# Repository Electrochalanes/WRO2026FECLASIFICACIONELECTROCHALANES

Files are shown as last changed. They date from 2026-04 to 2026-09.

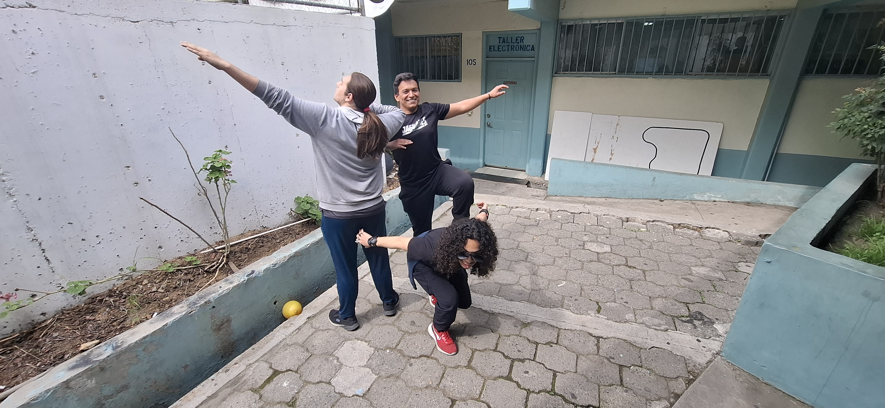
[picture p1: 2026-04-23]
t-photos/funnyphoto.jpg

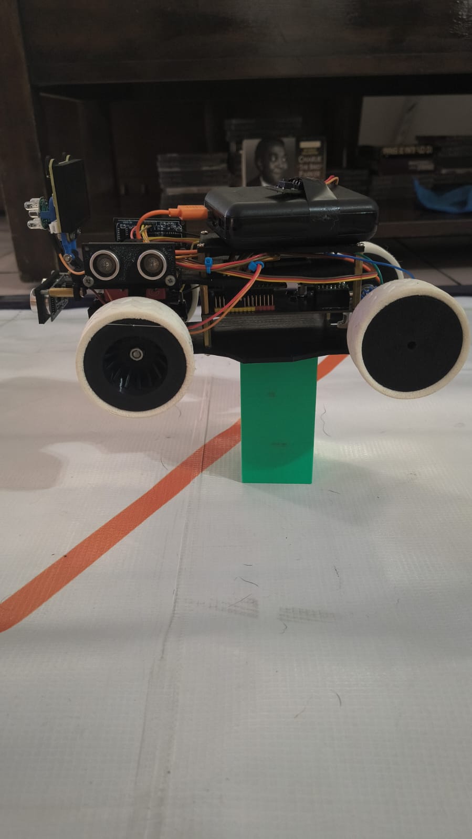
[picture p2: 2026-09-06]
v-photos/left.jpeg

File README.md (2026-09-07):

# Electrochalanes — WRO Future Engineers 2026 - Autonomous Self-Driving Car 🇲🇽

---

## Team

**Electrochalanes** — Tijuana, Baja California, Mexico

---

## Changelog

| Version | Date scope | Key changes |
|---|---|---|
| v1.0 | 2025 national competition | Baseline chassis, standard steering, single lateral sensor (Arduino UNO). |
| v2.0 | Early 2026 season | Bilateral PID (left + right sensors), Ackermann steering geometry, TPU tires, WonderCam color-based turn detection. |
| **v3.0 (current)** | **2026 Nationals** | **Migrated main controller from Arduino UNO R4 Minima to ESP32 + custom shield. Chassis and steering linkage reprinted in black PETG. Open Challenge control strategy rewritten (camera removed, adaptive single-wall PID). Obstacle Challenge gained a parking-exit maneuver and a two-tier (proportional + full-evasion) pillar strategy. Robot assembly video added.** |

This section exists specifically to give reviewers a fast way to see what changed between hardware/software revisions, in addition to the detailed reasoning in each section below.

---

## Repository Contents

| Folder | Contents |
|---|---|
| `t-photos` | 2 team photos (official + fun) |
| `v-photos` | 6 vehicle photos (all sides, top and bottom) |
| `video` | `video.md` with links to autonomous driving demonstrations for both challenges, **plus a full step-by-step robot assembly video** |
| `schemes` | Wiring and electromechanical diagrams (including the custom ESP32 shield) |
| `src` | Complete, commented control software for all programmed components |
| `models` | 3D-printable STL files for custom vehicle parts (now sliced for black PETG) |

---

## Introduction

This repository documents the complete engineering process of our autonomous vehicle for the **WRO Future Engineers 2026**.

As of this revision, the vehicle's main controller is an **ESP32** dev board paired with a **custom shield** (see [Components](#components) and [Power and Sensor Architecture](#2-power-and-sensor-architecture)), replacing the Arduino UNO R4 Minima used previously. The control software is split into two independent sketches, one per challenge:

**Open Challenge** (`src/OpenChallengeNationalsCode.ino`) is organized around:
1. **Sensor module** — sequential HC-SR04 readings (front, left, right)
2. **Adaptive single-wall PID controller** — follows whichever side wall was closer at the start of the run
3. **Corner-direction & turn sequencer** — determines and executes 90° turns using ultrasonic data only (the WonderCam camera is **no longer used** in this challenge — see [Open Challenge — Software Architecture](#open-challenge--software-architecture))
4. **Lap/corner counter and final-stop routine**

**Obstacle Challenge** (`src/ObstaclesChallengeNationalsCode.ino`) is organized around:
1. **Sensor module** — HC-SR04 front/left/right + push-button start trigger
2. **Vision module** — WonderCam color detection (red/green traffic pillars)
3. **Two-tier evasion strategy** — proportional visual steering while a pillar is far away, full stop-reverse-swerve maneuver once it's close
4. **Corner FSM** — 90° turns with a reverse/repositioning phase
5. **Parking-exit sequencer** *(new)* — multi-phase maneuver to leave the starting parking box in the direction with more clearance
6. **Lap/corner counter and stop routine**

To compile and upload either sketch: install **Arduino IDE 2.x**, add the **ESP32 board package** ("esp32" by Espressif Systems, via Boards Manager → additional URL `https://raw.githubusercontent.com/espressif/arduino-esp32/gh-pages/package_esp32_index.json`), install the **ESP32Servo** library (the standard `Servo` library is not compatible with the ESP32's PWM/LEDC peripheral) and, for the Obstacle Challenge sketch only, the **WonderCam** library. Open the corresponding `.ino` file, select your board's exact ESP32 dev-module variant, choose the correct COM port, and click Upload. Serial output is enabled at 115200 baud for live debugging via the Arduino IDE Serial Monitor.

---

## Components

| Component | Model | Purpose |
|---|---|---|
| Main controller | **ESP32 dev board** (WROOM-32-based DevKit) | Central processing — sensor reading, PID, motor and servo control |
| **Custom shield** | **Team-designed** | Consolidates all wiring (motor driver, servo, 3× HC-SR04, WonderCam I²C bus, start button) onto a single board mounted on the ESP32's headers, in place of the breadboard wiring used with the Arduino UNO R4 Minima. See [Power and Sensor Architecture](#2-power-and-sensor-architecture) for the electrical reasoning behind it. |
| DC motor driver | TB6612FNG Dual Motor Driver | Bidirectional speed control via PWM |
| Drive motor | 50:1 Micro Metal Gearmotor HPCB 6V | Forward traction |
| Steering servo | Digital Servomotor TD-8125 | Directional control via Ackermann steering |
| Ultrasonic sensor ×3 | HC-SR04 | Front wall detection + wall-following / corner detection |
| Color camera | Hiwonder WonderCam V2.0 | Detects red/green traffic pillars (Obstacle Challenge only) |
| Start button | Push button (Pin 34, `INPUT_PULLUP` + external pull-up on the shield) | Triggers start sequence per WRO rules 9.10–9.11 |
| Logic power | 5V 3A power bank | Supplies the ESP32, sensors, camera, and servo |
| Motor power | 7.4V 400 mAh LiPo | Dedicated traction supply, isolated from logic |
| Structure | **Black PETG** (chassis frame, sensor mounts, steering linkage), TPU (tires), acrylic (base plate), M3/M5 screws, M5/M16 bearings | Chassis, tires, and mechanical assembly |

> **Note on the ESP32 dev board model:** any WROOM-32-based ESP32 DevKit-style board works with the pin map used in the sketches (GPIOs 5, 12–14, 17–19, 21, 22, 32–35). If your team's exact board/module differs, update this row with the precise part number and add its pinout diagram to `schemes/`.

### Why ESP32 instead of the Arduino UNO R4 Minima?

| Consideration | Arduino UNO R4 Minima | ESP32 | Why it mattered for us |
|---|---|---|---|
| Clock speed / headroom | 48 MHz | 240 MHz (dual-core) | More margin for the camera-driven decision logic in the Obstacle Challenge sketch, without slowing down sensor polling. |
| GPIO count | Limited | More available I/O | Needed extra pins once the parking-exit and dual-servo-pin-mapping requirements were added. |
| Native PWM/servo support | `Servo` library, hardware timers shared with other peripherals | Dedicated LEDC PWM peripheral via `ESP32Servo` | Frees up timer conflicts we previously had to work around. |
| I/O voltage | 5V-tolerant | **3.3V-only** | Introduced a real integration risk — see the level-shifting note below. |

**Engineering risk introduced by the migration (and why the custom shield exists):** the HC-SR04's ECHO output is a 5V logic signal, but every ESP32 GPIO is rated for 3.3V input only — driving an ECHO pin directly from a 5V sensor risks damaging the microcontroller over repeated use. Additionally, GPIO34 (used for the start button) is one of the ESP32's *input-only* pins and, unlike most other GPIOs, has **no internal pull-up/pull-down resistor at all**, so `pinMode(PIN_BOTON, INPUT_PULLUP)` in software does not actually provide one. The custom shield exists to solve both problems in one board: resistor voltage dividers on the three ECHO lines (stepping 5V down into the ESP32's safe range) and an external pull-up resistor on the button line, in addition to simply consolidating what used to be loose breadboard wiring. 

### Shield Design and Power Distribution

No commercial board combines an ESP32 with a TB6612FNG H-bridge in the footprint we needed — the few options that exist are either pin-incompatible or considerably larger than necessary. Rather than continuing to wire both onto a breadboard, we designed our own pin-expansion shield: laid out like any commercial ESP32 shield, but with its header arrangement built specifically around the H-bridge.

**How it's wired:**
- Power comes in through a barrel jack or the USB-C port.
- That input feeds a regulator that steps 5V down to the ESP32's native 3.3V logic supply.
- The ESP32's header pins are fed directly from the unregulated input rail rather than through that regulator, so raw 5V is still available at the header for peripherals that need it, separate from the ESP32's own regulated 3.3V.
- A few ESP32 GPIOs are wired exclusively to the TB6612FNG and aren't broken out to the general-purpose header at all; the driver needs them, so they're still fully usable from code, just not available for anything else on the shield.
- The TB6612FNG's logic side shares the ESP32's rail, but the motor supply comes directly from the main power input, bypassing the regulator.
---

## 1. Mobility and Mechanical Design

### Chassis and Steering System

The vehicle's structure is based on our 2025 national competition design, with an **Ackermann steering geometry** on the front axle. Ackermann geometry ensures that during a turn, the inner wheel follows a tighter arc than the outer wheel — eliminating lateral tire slip and reducing friction in tight corners. This improves trajectory repeatability, which is critical when relying on a time-based turn duration instead of a gyroscope.

**Material update (v3.0):** the chassis frame, sensor mounts, and the **steering linkage rod** are now printed in **black PETG**, replacing the PLA used previously. Compared to PLA, PETG has meaningfully higher impact resistance and layer adhesion, at a modest cost in stiffness and print-surface finish — a favorable trade for the steering rod specifically, since it is a component under repeated cyclical mechanical stress every time the Ackermann linkage moves. Tires remain **TPU** (grip and vibration absorption).

M3 screws handle small brackets and sensor attachments; M5 screws with M5/M16 bearings handle the steering pivot and rear axle, ensuring low friction under load.

### Drive Motor Selection

The **50:1 Micro Metal Gearmotor HPCB 6V** (0.74 kg·cm stall torque, ~650 rpm no-load) was selected after evaluating two options:

| Option | Ratio | Speed | Torque | Result |
|---|---|---|---|---|
| **Chosen: HPCB 6V 50:1** | 50:1 | ~650 rpm | 0.74 kg·cm | ✅ Sufficient torque, controllable speed for closed-loop control |
| Discarded: high-speed motor | 10:1 | ~3000 rpm | ~0.15 kg·cm | ❌ Too fast — the control loop could not correct lateral drift in time |

The 50:1 ratio provides enough torque to accelerate smoothly while keeping speed low enough for the wall-following controller to react before lateral drift exceeds recoverable limits. This reasoning is unchanged by the ESP32 migration; the motor and driver stage were not modified.

### Iteration History

| Version | Change | Reason |
|---|---|---|
| V1 (2025) | Standard steering, single lateral sensor | Baseline from 2025 national competition |
| V2 | Bilateral PID using left + right sensors | V1 drifted toward the wider wall; bilateral error fixed this |
| V3 | Ackermann steering geometry, TPU tires | Standard steering caused ~8° corner angle error per turn due to tire slip |
| **V4 (current)** | **ESP32 + custom shield; black PETG chassis and steering rod; Open Challenge vision removed in favor of adaptive single-wall PID; Obstacle Challenge gained a parking-exit maneuver** | **More processing headroom and I/O for the added parking-exit logic; PETG's toughness over PLA for the steering linkage; simplifying the Open Challenge control loop by removing a camera dependency that wasn't needed once the sensor-only cornering logic proved reliable** |

---

## 2. Power and Sensor Architecture

### Power Budget

Two independent power rails isolate motor switching noise from logic and sensor signals. Figures below are typical component ratings for this hardware revision; **please re-verify with a multimeter on your actual assembled shield**, since exact draw depends on the ESP32 board variant and shield regulation.

**Rail 1 — Logic (5V, 3A power bank):**

| Component | Current (approx.) |
|---|---|
| ESP32 dev board (Wi-Fi/Bluetooth unused) | ~150 mA |
| WonderCam V2.0 *(Obstacle Challenge sketch only)* | ~300 mA |
| 3× HC-SR04 sensors | ~45 mA total (~15 mA each) |
| TD-8125 servo (peak) | ~1,500 mA |
| TB6612FNG logic stage | <10 mA |
| **Total peak — Obstacle Challenge (camera active)** | **~2,005 mA** |
| **Total peak — Open Challenge (no camera in this sketch)** | **~1,705 mA** |

Servo peaks are short and do not coincide with ESP32 or camera peaks, so worst-case sums are conservative.

**Rail 2 — Traction (7.4V, 400 mAh LiPo):**

| Component | Current |
|---|---|
| 50:1 gearmotor (peak) | ~1,500 mA |
| TB6612FNG power stage | ~100 mA |
| **Total peak** | **~1,600 mA** |

Estimated autonomy: 0.4 Ah ÷ 1.6 A = **~15 minutes** — more than sufficient for 3-minute runs. This estimate is unchanged from the previous hardware revision, since the traction rail was not modified.

> **Why two rails?** During early testing, motor acceleration caused voltage dips on a shared supply that reset the microcontroller mid-run. Splitting into two independent rails eliminated this failure mode entirely, and the same reasoning carried over unchanged to the ESP32 migration.

### Sensor Selection and Placement

**Why HC-SR04?**
The HC-SR04 is a widely available, cost-effective sensor with a well-documented standard protocol (10 µs HIGH trigger pulse, echo read on HIGH), reliable performance at the distances used in this competition (10–200 cm), and straightforward integration via `pulseIn`. Its main integration cost on this hardware revision is the 5V/3.3V logic mismatch discussed above, addressed via the custom shield's level shifting.

| Sensor | Position | Height | Justification |
|---|---|---|---|
| Front | Center-front of chassis | 12 cm | Avoids reading the floor; detects walls reliably from the corner-trigger distance used by each challenge |
| Left | Above front-left wheel | 10 cm | Reads lateral wall distance for wall-following; positioned forward to detect walls before the chassis passes them |
| Right | Above front-right wheel | 10 cm | Symmetric to left, used interchangeably depending on which side the controller decides to follow |

The WonderCam (Obstacle Challenge only) is mounted facing forward/down, positioned to detect red and green traffic pillars ahead of the vehicle and to compute each pillar's horizontal position and bounding-box area.

### Pin Map

The two sketches assign a few pins differently, because the Obstacle Challenge sketch needs the ESP32's default I²C pins (GPIO21/22) for the WonderCam, while the Open Challenge sketch is free to use GPIO21 for the servo instead:

| Signal | Open Challenge | Obstacle Challenge |
|---|---|---|
| Front TRIG / ECHO | 33 / 19 | 33 / 19 |
| Right TRIG / ECHO | 18 / 5 | 18 / 5 |
| Left TRIG / ECHO | 32 / 35 | 32 / 35 |
| Steering servo | **21** | **17** |
| I²C SDA / SCL (WonderCam) | *not used* | **21** / 22 |
| Start button | 34 | 34 |
| Motor PWM / AIN1 / AIN2 | 14 / 12 / 13 | 14 / 12 / 13 |

---

## Open Challenge — Software Architecture

The Open Challenge no longer uses the WonderCam at all. Turn direction and lane-keeping are both derived purely from the three HC-SR04 sensors. This is a deliberate simplification from the previous camera-based approach: once the sensor-only cornering logic (comparing which side opens up at a corner) proved reliable in testing, the camera dependency added complexity without adding accuracy for this challenge, so it was removed. The Obstacle Challenge sketch still uses the camera, since it needs to identify pillar *color*, which distance sensors cannot do.

### Control Flow

```
                     ┌────────────────────────┐
                     │  IDLE (button not yet   │
                     │  pressed)                │
                     └───────────┬─────────────┘
                                 │ button press
                                 ▼
                   Capture initial left/right distance
                   as PID setpoints → follow whichever
                   side is CLOSER for the whole run
                                 │
                                 ▼
                     ┌────────────────────────┐
             ┌──────►│   WALL-FOLLOWING PID    │
             │       │ (single sensor, fixed   │
             │       │  setpoint from start)   │
             │       └───────────┬─────────────┘
             │                   │ front < DISTANCIA_GIRO
             │                   │ AND one side opens up
             │                   ▼
             │       ┌────────────────────────┐
             │       │   CORNER TURN           │
             │       │ (first corner picks &   │
             │       │  locks the direction;   │
             │       │  later corners repeat   │
             │       │  the same direction)    │
             │       └───────────┬─────────────┘
             │                   │ corner count < 12
             └───────────────────┘
                                 │ corner count == 12
                                 ▼
                     Drive straight briefly, stop
```

### Algorithm 1 — HC-SR04 Sequential Reading

All three sensors are read one at a time every loop cycle:

```cpp
float leerDistancia(int trig, int echo) {
  digitalWrite(trig, LOW);
  delayMicroseconds(2);
  digitalWrite(trig, HIGH);
  delayMicroseconds(10);          // HC-SR04: 10 µs HIGH pulse to trigger
  digitalWrite(trig, LOW);
  unsigned long duracion = pulseIn(echo, HIGH, 30000);   // 30 ms timeout -> ~5 m max range
  if (duracion == 0) return -1;
  return duracion / 58.0;         // standard HC-SR04 time-of-flight -> cm conversion
}
```

A reading of `-1` (timeout) is treated as "no update" rather than "wall is very far": the loop only overwrites `ulLecturaFrente/Der/Izq` when a reading is valid, so a single dropped echo doesn't erase a good previous reading.

### Algorithm 2 — Adaptive Single-Wall PID

Rather than the previous bilateral (left-minus-right) centering controller, this revision follows **one wall only**, chosen at the start of the run:

```cpp
// At start: capture each side's distance as that side's setpoint
setpoint_Der = (ulLecturaDer < 400) ? ulLecturaDer : 40.0;
setpoint_Izq = (ulLecturaIzq < 400) ? ulLecturaIzq : 40.0;

// Whichever side is CLOSER (smaller setpoint) is the one that gets followed
if (setpoint_Der > setpoint_Izq) {
  opcion_2 = 1;   // right wall is farther -> follow the (closer) left wall
} else {
  opcion_2 = 2;   // left wall is farther (or equal) -> follow the (closer) right wall
}
```

```cpp
void PIDderecho() {
  error = ulLecturaDer - setpoint_Der;

  double P = Kp * error;
  double D = Kd * ((error - error_anterior) / dt);
  // Conditional integration: only accumulate the integral if doing so keeps
  // the *unclamped* output inside the same band the final output is
  // clamped to — a simple anti-windup trick.
  double prueba = P + D + Ki * (suma_errores + error * dt);
  if (constrain(prueba, -20, 20) == prueba) {
    suma_errores += error * dt;
    suma_errores = constrain(suma_errores, -70, 70);
  }
  double I = Ki * suma_errores;
  double salidaPID = constrain(P + I + D, -20, 20);

  int anguloServo = CENTRO + (int)salidaPID;
  moverServo(anguloServo);
  adelante(VEL_NORMAL);
  error_anterior = error;
}
```

`PIDizquierdo()` mirrors this exactly, with the error sign flipped (`setpoint_Izq - ulLecturaIzq`) so that a positive PID output always means "steer right" under both functions, using the same gains and clamps.

**Why adaptive-setpoint single-wall following instead of bilateral centering?** Bilateral centering (error = left − right) is setpoint-free and adapts automatically to any corridor width, which is why V2 used it. The trade-off is that it requires both sensors to be reliable simultaneously. The single-wall approach trades that generality for simplicity: it commits to one wall at the start (whichever is closer, and therefore whichever gives a stronger, more reliable signal) and only needs that one sensor to behave well for the rest of the run. This is a deliberate simplification, not strictly an improvement — teams reproducing this design should note it assumes a roughly consistent corridor width within a round, since a mid-run corridor-width change would not be compensated for the way bilateral centering would.

**Tuning (current gains):**

| Kp | Ki | Kd |
|---|---|---|
| 10.0 | 0.05 | 5.0 |

Note these gains are **not directly comparable in magnitude** to the previous bilateral controller's `Kp=1.2, Ki=0.04, Kd=0.15`, since the earlier controller's error term was the difference of two sensors (typically small, since both sides are similar magnitudes) while this one's error term is a single sensor's raw deviation in cm from a fixed setpoint (potentially larger swings) — a like-for-like re-tune was required after the algorithm change, not just a hardware swap.

### Algorithm 3 — Turn Direction and Cornering (Sensor-Only)

A corner is recognized when the front sensor reads closer than `DISTANCIA_GIRO` (80 cm) **and** at least one lateral sensor reads more than 100 cm — the second condition distinguishes an actual corner opening from simply being close to a wall in a narrow straight.

```cpp
if (opcion == 0) {
  // First corner: stop, let the chassis settle, then re-read both sides
  detenerRobot();
  delay(1500);
  float lIzq = leerDistancia(TRIG_IZQ, ECHO_IZQ);
  float lDer = leerDistancia(TRIG_DER, ECHO_DER);
  if (lIzq > 0) ulLecturaIzq = lIzq;
  if (lDer > 0) ulLecturaDer = lDer;

  // Turn toward whichever side has more open space — that's where the track continues
  if (ulLecturaIzq > ulLecturaDer) {
    opcion = 1;       // more room on the left -> turn left at every corner from now on
    girarIzquierda();
  } else {
    opcion = 2;       // more room on the right -> turn right at every corner from now on
    girarDerecha();
  }
} else if (opcion == 1) {
  girarIzquierda();   // keep the same direction as the first corner
} else if (opcion == 2) {
  girarDerecha();
}
```

`girarIzquierda()`/`girarDerecha()` are open-loop, timed maneuvers: steer to full lock, drive through the corner for `TGIRO` ms, recenter, then drive straight for `TFront` ms before the PID loop resumes (this last step gives the chassis room to clear the corner before its lateral readings are trusted again).

This replaces the previous WonderCam-based turn detection entirely. There is no fallback path needed here (unlike the old camera-based version, whose fallback *was* this same sensor comparison) — this **is** now the only mechanism.

### Edge Cases

| Situation | Behavior |
|---|---|
| Front sensor timeout (`-1`) mid-run | Last known-good front reading is kept; a corner is not spuriously triggered by a single dropped echo |
| Both lateral sensors read ≥ 400 cm at start | Both setpoints default to 40 cm |
| `dt` computed as ~0 (very fast consecutive loop iterations) | Clamped to a 0.001 s minimum to avoid a divide-by-zero in the derivative term |
| 12th corner completed | Drives straight for `TFinal` ms to clear the area, then stops for good |

---

## Obstacle Challenge — Software Architecture

### Overview

The Obstacle Challenge program combines: a start-of-run **parking-exit maneuver**, a **two-tier pillar-evasion strategy** driven by the WonderCam, and a **corner FSM** for the track's 90° turns. A lap counter (`contadorGiros`) tracks completed corners; after 12 corners (3 laps) the run stops.

### Priority Order

Each `loop()` pass (throttled to ~10 Hz for the decision logic, while sensors are still polled every cycle) evaluates, in order:

1. **Start button** — arms the robot and, on the very first press, triggers the parking-exit maneuver (per WRO rule: the vehicle must not move until the operator releases it)
2. **Color detection & evasion decision** — if either pillar color is in view, this branch takes over exclusively for that cycle
3. **Corner detection** — only checked when no pillar is currently in view; triggers the corner FSM if the front wall is close and a side is open

### Corner FSM

```
DRIVING STRAIGHT ──(front < DISTANCIA_FRENTE AND a side is open)──► TURN (steer to lock, drive Tgiro ms)
                                                                          │
                                                                (pause Talto ms)
                                                                          │
                                                                          ▼
                                                                REVERSE, wheel angled
                                                                (Tatras ms)
                                                                          │
                                                                          ▼
                                                        contadorGiros++ → DRIVING STRAIGHT
                                                        (if contadorGiros == 12 → STOP)
```

```cpp
void girarDerecha() {
  moverServo(Acentral + 40);
  adelante(VELOCIDAD_GIRO);
  delay(Tgiro);
  moverServo(Acentral);
  detenerRobot();
  delay(Talto);
  moverServo(Areversa);        // wheel angled while reversing, to help straighten the heading
  atras(VELOCIDAD_GIRO);
  delay(Tatras);
  detenerRobot();
  delay(500);
  adelante(VELOCIDAD_NORMAL);
  moverServo(Acentral);
  delay(1000);
}
```

`girarIzquierda()` mirrors this for left turns.

### Algorithm — Two-Tier Pillar Evasion

Rather than a single fixed-distance trigger, the current logic reacts differently depending on how close a pillar is:

- **Far away** (bounding-box area below threshold): a light **proportional** nudge keeps the pillar roughly centered in frame, without committing to a full evasion yet:
  ```cpp
  int angulo = map(centroX, 0, 320, 51, 111);
  moverServo(constrain(angulo, 51, 111));
  adelante(VELOCIDAD_NORMAL);
  ```
- **Close enough** (bounding-box area above threshold): a full 3-phase evasion maneuver runs — reverse briefly, swerve past the pillar on the rule-mandated side, drive straight, then swerve back to center:
  ```cpp
  void esquivarRojo() {          // passes a RED pillar on the RIGHT, per WRO rules
    detenerRobot();
    delay(500);
    atras(VELOCIDAD_NORMAL);
    delay(500);
    detenerRobot();
    delay(500);
    adelante(VELOCIDAD_ESQUIVE);
    moverServo(AesquiveRojo + 10);
    delay(Tesquive);
    adelante(VELOCIDAD_ESQUIVE);
    moverServo(Acentral);
    delay(Tcentral);
    adelante(VELOCIDAD_ESQUIVE);
    moverServo(AreacomodoRojo - 10);
    delay(Treacomodo + 200);
    moverServo(Acentral);
  }
  ```
  `esquivarVerde()` mirrors this, steering left instead, to pass a **GREEN** pillar on the **LEFT** — also per WRO rules.

### Algorithm — Parking-Exit Maneuver *(new)*

On the first button press, the robot reads which side of the parking box has more clearance and executes a fixed 5-phase sequence to back out of it — the same alternating forward/reverse, opposite-lock pattern a person uses to exit a tight parallel parking spot:

| Phase | Action | Steering | Duration |
|---|---|---|---|
| 1 | Forward | Full lock, away from the box | `Tadelante_salida` (350 ms) |
| 2 | Reverse | Full lock, opposite way | `Tatras_salida` (300 ms) |
| 3 | Forward | Full lock, away from the box | `Tadelante_afuera` (1000 ms) |
| 4 | Forward | Full lock, opposite way | `Tadelante_afuera` (1000 ms) |
| 5 | Reverse | Full lock, away from the box | `Tatras_Acomodo` (600 ms) |

```cpp
void salirEstacionamientoDerecha() {
  moverServo(Asalida_derecha);
  adelante(Velocidad_salida);
  delay(Tadelante_salida);
  detenerRobot();
  delay(500);
  moverServo(Asalida_izquierda);
  atras(Velocidad_salida);
  delay(Tatras_salida);
  detenerRobot();
  delay(500);
  moverServo(Asalida_derecha);
  adelante(Velocidad_salida);
  delay(Tadelante_afuera);
  detenerRobot();
  delay(500);
  moverServo(Asalida_izquierda);
  adelante(Velocidad_salida);
  delay(Tadelante_afuera);
  detenerRobot();
  delay(500);
  moverServo(Asalida_derecha);
  atras(Velocidad_salida);
  delay(Tatras_Acomodo);
  detenerRobot();
}
```

`salirEstacionamientoIzquierda()` is the mirror image, used when the left side has more clearance. Whichever side is chosen here (`opcion`) is reused for every corner turn direction for the rest of the run, keeping the exit direction and the lap direction consistent.

**Known scope limitation:** after the 12th corner, the robot simply stops where it is — there is currently no automated maneuver to return to and re-park inside the parking box. This is a reasonable next iteration if the team wants to pursue the final-parking bonus described in the rulebook (Section 6, "Estacionamiento en el cajón de estacionamiento").

### Edge Cases

| Situation | Behavior |
|---|---|
| Green detection too low in frame (`centroY2 > 150`) | Treated as noise (block likely already alongside/behind the robot) and its area is zeroed out |
| Pillar detected while mid-corner-turn | Corner maneuvers are blocking (`delay`-based), so a pillar can't interrupt one already in progress |
| No pillar and no corner condition | Drive straight at `VELOCIDAD_NORMAL`, keep polling |
| Camera update fails (`Cam.updateResult()` returns false) | Cycle is skipped (`return`) rather than acting on stale/garbage data |

---

## Obstacle Challenge — Source Code

The complete, commented source for both challenges lives at:
- `src/open_challenge/OpenChallengeNationalsCode.ino`
- `src/obstacle_challenge/ObstaclesChallengeNationalsCode.ino`

---

## 4. Systems Thinking and Engineering Decisions

### Subsystem Interaction

```
[Power Bank 5V] ──► [ESP32 + Custom Shield] ──► [TB6612FNG] ◄── [LiPo 7.4V]
                               │                       │
                    ┌──────────┼──────────┐       [DC Motor 50:1]
                    │          │          │
              [WonderCam*]  [3× HC-SR04] [Servo TD-8125]
                    │          │          │
             [Color/Pillar [Wall-follow /  [Ackermann
              detection*]   corner detect]  Steering]

  * WonderCam and color detection are used in the Obstacle Challenge sketch only.
```

### Trade-offs

**ESP32 migration vs. staying on Arduino UNO R4 Minima:** more processing headroom and I/O simplified adding the parking-exit logic and the dual pin-map needed once the camera's I²C bus competed for GPIO21. The cost was a genuine integration risk (3.3V-only logic against 5V sensors, and a button pin with no internal pull resistor), which is why a custom shield was designed rather than wiring the ESP32 directly the way the Arduino board had been.

**PETG vs. PLA for the chassis and steering rod:** PETG's added toughness directly targets the steering linkage, a component under repeated cyclic load every time the Ackermann geometry articulates; the trade-off is a small step down in dimensional stiffness and print finish compared to PLA, which was judged acceptable for a functional part that isn't a wear-tolerance-critical fit.

**Removing the camera from the Open Challenge vs. keeping bilateral PID + vision fallback:** simplifies the sketch and removes one sensing dependency, at the cost of losing bilateral centering's automatic adaptation to changing corridor width mid-run. Given the Open Challenge's corridor width is fixed for the duration of a single round, this trade was judged acceptable.

**Two-tier pillar evasion vs. a single fixed-distance trigger:** reacting proportionally while a pillar is still far away, and only committing to the full blocking evasion maneuver once it's close, reduces unnecessary full stops when a pillar is visible but not yet actually in the vehicle's path.

**Time-based vs. gyroscope-based turns:** unchanged reasoning from previous versions — a gyroscope would give exact 90° turns, but time-based turns avoid the extra wiring and failure points of an IMU, and remain reliable as long as battery voltage is consistent (guaranteed by the dedicated LiPo traction rail).

### Risk Assessment

| Risk | Mitigation |
|---|---|
| ESP32 GPIO damage from 5V HC-SR04 echo signals | Voltage-divider level shifting on the shield (see [Components](#components)) |
| Unreliable button reads (GPIO34 has no internal pull resistor) | External pull-up resistor on the shield |
| Wi-Fi/Bluetooth radios interfering with rule 11.10 compliance | Sketches never initialize either radio; verify this remains true in any future firmware update |
| Corner never detected (front/lateral sensor timeout at the critical moment) | Last known-good reading is retained rather than reset to zero, avoiding a spurious "wall is gone" false read |
| Servo command outside a safe range (Obstacle sketch's `moverServo()` doesn't `constrain()`) | All current constants are within [45°, 135°], a safe range for the TD-8125; recommend adding a `constrain()` call to match the Open Challenge sketch's safer implementation |

---

## 5. Configurable Parameters — Open Challenge

| Constant | Default | Description |
|---|---|---|
| `CENTRO` | 81 | Servo angle for straight-ahead driving |
| `VEL_NORMAL` | 180 | Cruise motor speed (PWM 0–255) |
| `VEL_GIRO` | 210 | Motor speed during a corner |
| `DISTANCIA_GIRO` | 80 cm | Front distance that triggers a turn |
| `TOTAL_GIROS` | 12 | Total corners before automatic stop (3 laps × 4 corners) |
| `TGIRO` | 1400 ms | Duration of full-lock steering while driving through a corner |
| `TFront` | 1000 ms | Straight-driving duration right after a turn, before PID resumes |
| `TFinal` | 2400 ms | Straight-driving duration after the 12th corner, before stopping |
| `Kp` | 10.0 | PID proportional gain |
| `Ki` | 0.05 | PID integral gain |
| `Kd` | 5.0 | PID derivative gain |
| `setpoint_Der` / `setpoint_Izq` | captured at start (default 40 cm) | Target distance from whichever wall is being followed |

## Configurable Parameters — Obstacle Challenge

| Constant | Default | Description |
|---|---|---|
| `Acentral` | 80° | Servo angle for straight-ahead driving |
| `Areversa` | 51° | Steering angle while reversing after a right turn |
| `Asalida_izquierda` / `Asalida_derecha` | 45° / 135° | Full-lock angles used during the parking-exit maneuver |
| `AesquiveRojo` / `AreacomodoRojo` | 111° / 51° | Evasion / recovery angles for a red pillar |
| `AesquiveVerde` / `AreacomodoVerde` | 51° / 111° | Evasion / recovery angles for a green pillar |
| `VELOCIDAD_NORMAL` | 170 | Cruise motor speed (PWM 0–255) |
| `VELOCIDAD_GIRO` | 180 | Motor speed during a corner |
| `VELOCIDAD_ESQUIVE` | 200 | Motor speed during pillar evasion |
| `Velocidad_salida` | 190 | Motor speed during the parking-exit maneuver |
| `DISTANCIA_FRENTE` | 70 cm | Front distance that triggers a corner turn |
| `Tgiro` | 1600 ms | Duration of full-lock steering while driving through a corner |
| `Talto` | 500 ms | Pause at full lock before reversing after a corner |
| `Tatras` | 1000 ms | Reverse duration after a corner |
| `Tesquive` | 700 ms | Evasion phase 1 duration (initial swerve) |
| `Tcentral` | 700 ms | Evasion phase 2 duration (straight past the pillar) |
| `Treacomodo` | 500 ms | Evasion phase 3 duration (recovery swerve) |
| `Tadelante_salida` / `Tatras_salida` | 350 ms / 300 ms | Parking-exit phases 1–2 durations |
| `Tadelante_afuera` | 1000 ms | Parking-exit phases 3–4 durations |
| `Tatras_Acomodo` | 600 ms | Parking-exit phase 5 duration |
| `AREA_MINIMA_ROJO` | 3500 px² | Bounding-box area above which a red-triggered evasion fires (see code review note) |
| `AREA_MINIMA_VERDE` | 6000 px² | Bounding-box area above which a green-triggered evasion fires (see code review note) |
| `TOTAL_GIROS` | 12 | Total corners before automatic stop (3 laps × 4 corners) |

---

## Known Issues / Roadmap

This section exists so reviewers (and future us) can see open items at a glance, in addition to the trade-off reasoning above:

1. **No automated final parking maneuver** — the Obstacle Challenge run currently stops after the 12th corner rather than returning to the parking box.
2. **`moverServo()` without `constrain()` in the Obstacle Challenge sketch** — currently safe given the constants in use, but worth hardening to match the Open Challenge sketch.

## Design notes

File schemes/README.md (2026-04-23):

Electromechanical diagrams
====

This directory contains the electromechanical wiring diagram for the robot.

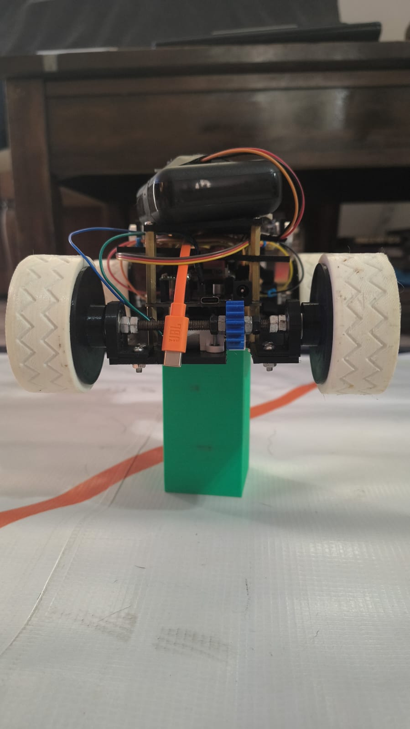
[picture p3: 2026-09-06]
v-photos/back.jpeg

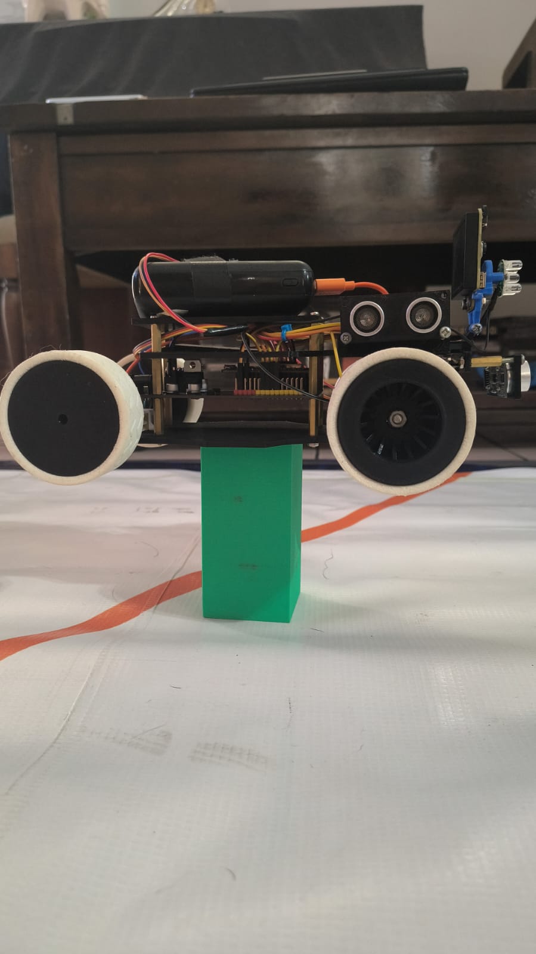
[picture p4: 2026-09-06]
v-photos/right.jpeg

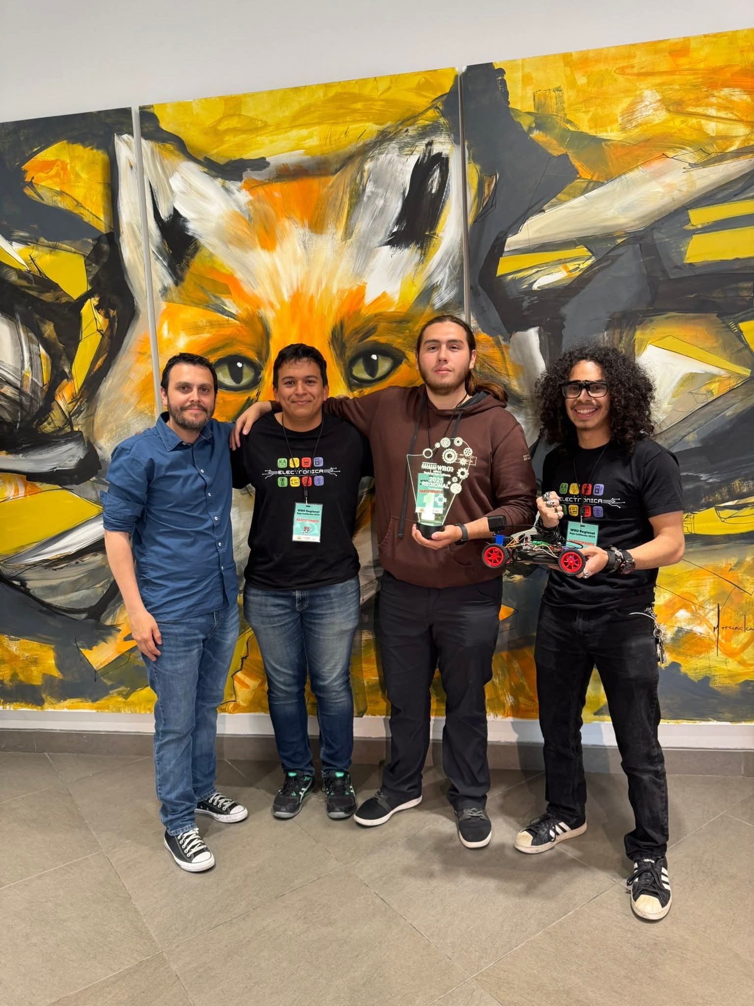
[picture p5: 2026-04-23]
t-photos/formalphoto.jpg

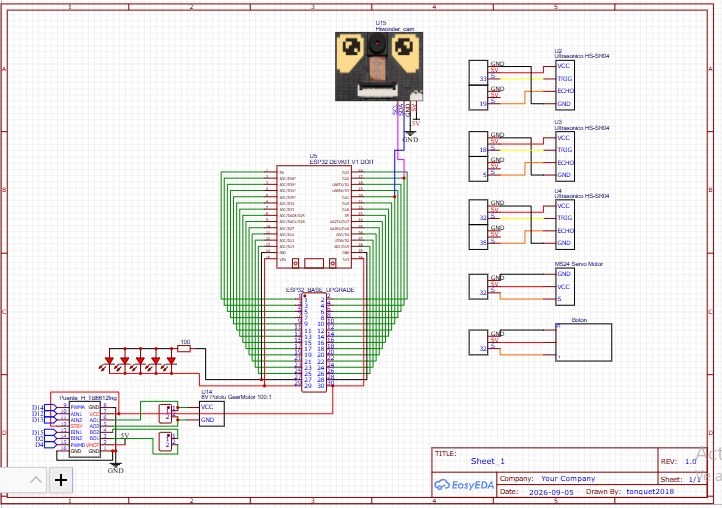
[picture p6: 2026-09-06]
schemes/WRO Nationals Robot.jpeg

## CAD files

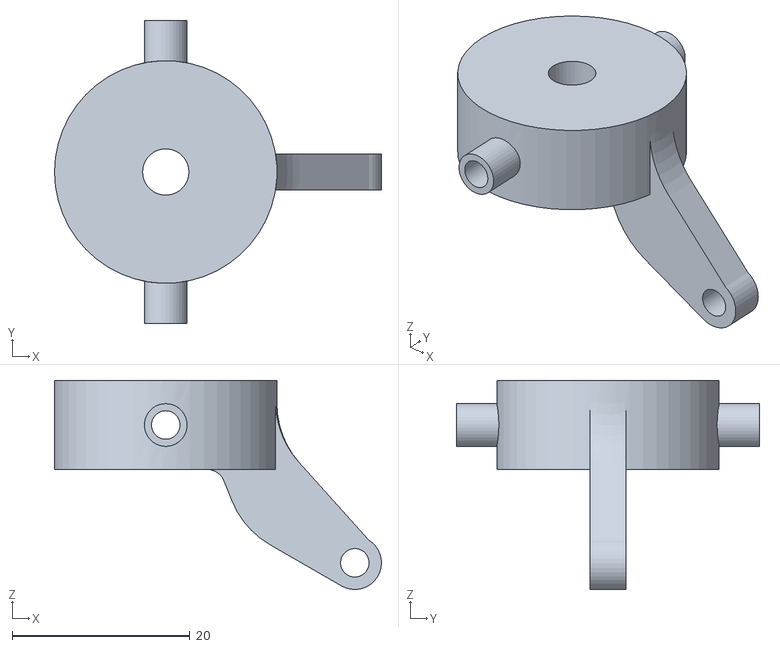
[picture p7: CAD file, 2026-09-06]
models/girador.STL
36.7 x 34.0 x 23.5

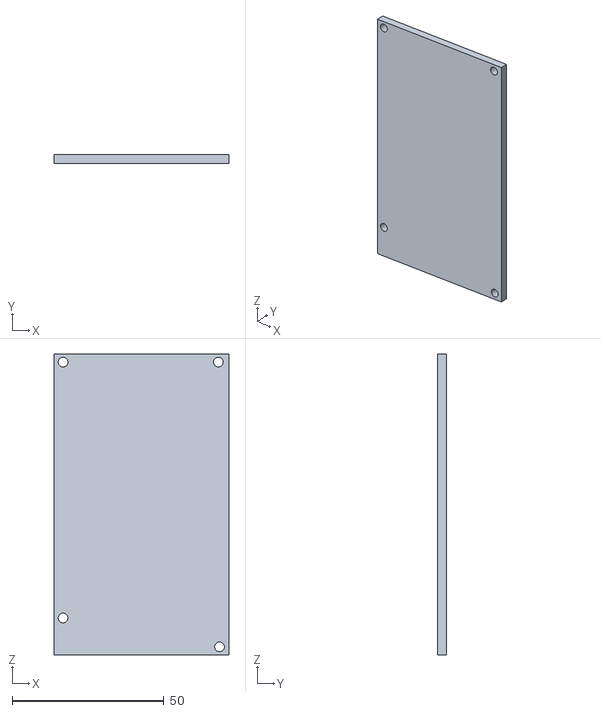
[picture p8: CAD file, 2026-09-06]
models/base esp.STL
57.5 x 3.00 x 99.2

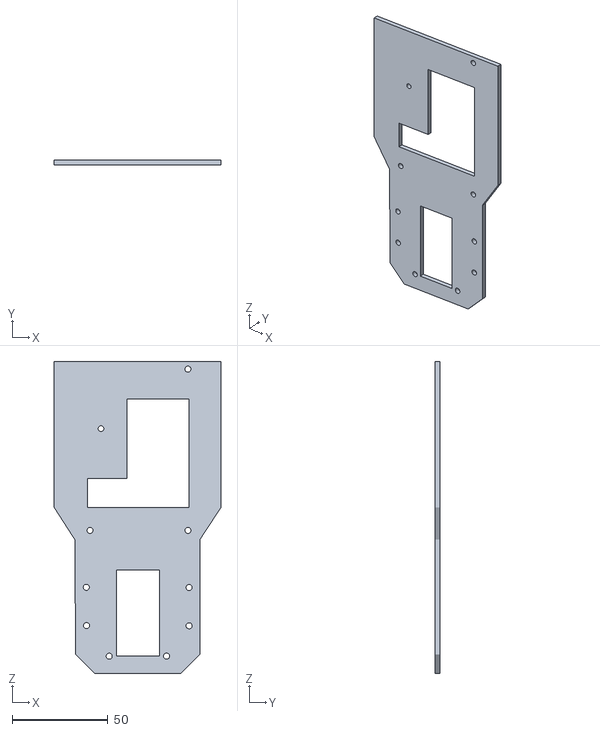
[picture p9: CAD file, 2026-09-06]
models/piso 2.STL
87.2 x 2.70 x 163.2

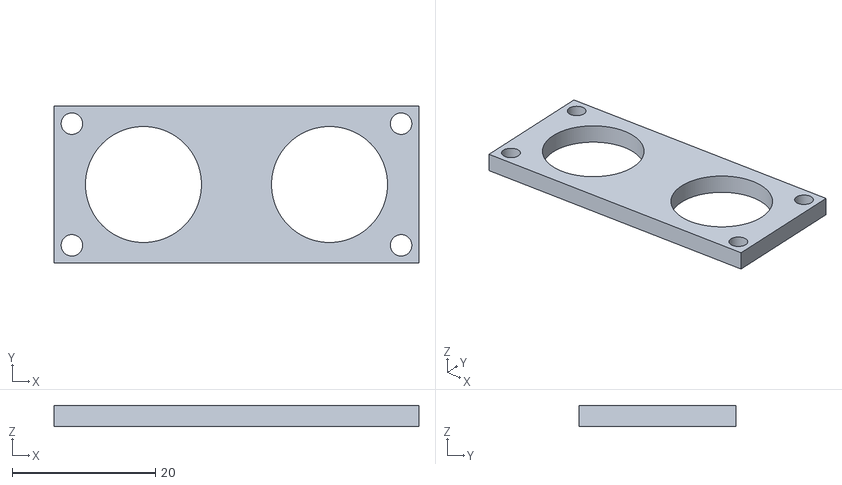
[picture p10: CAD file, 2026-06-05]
models/baseultrasónicos.stl
51.0 x 22.0 x 3.00

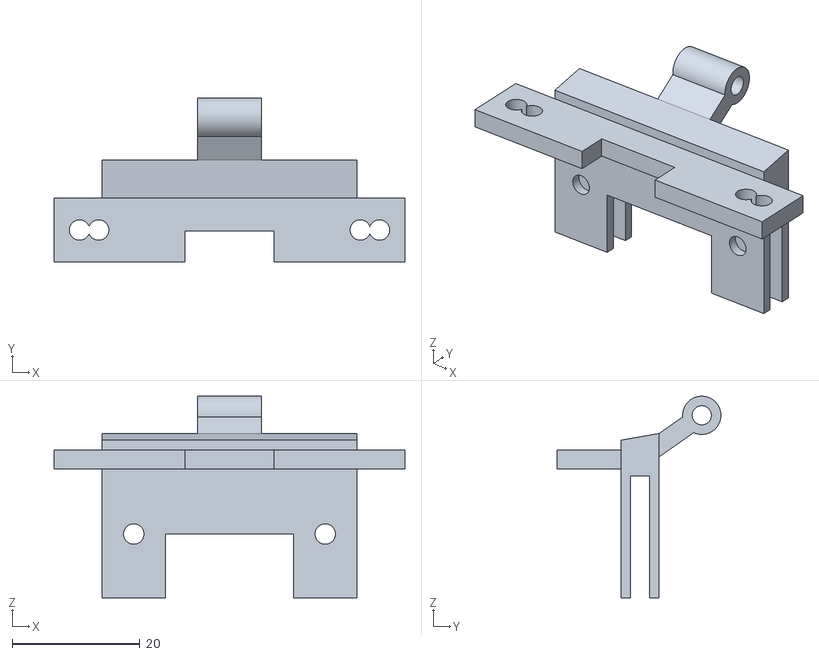
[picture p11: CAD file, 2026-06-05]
models/base camara - Part 1.stl
55.0 x 25.7 x 31.6

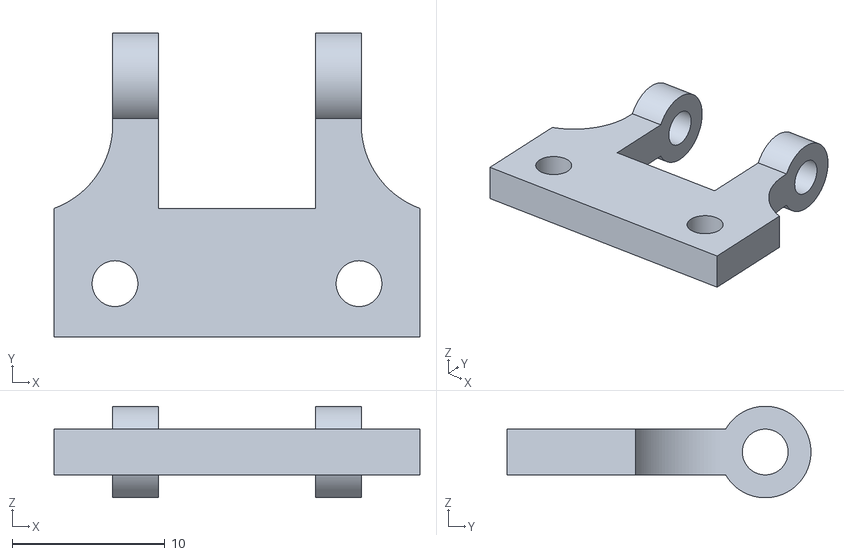
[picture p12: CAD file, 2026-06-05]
models/base camara - Part 2.stl
24.0 x 19.9 x 6.00

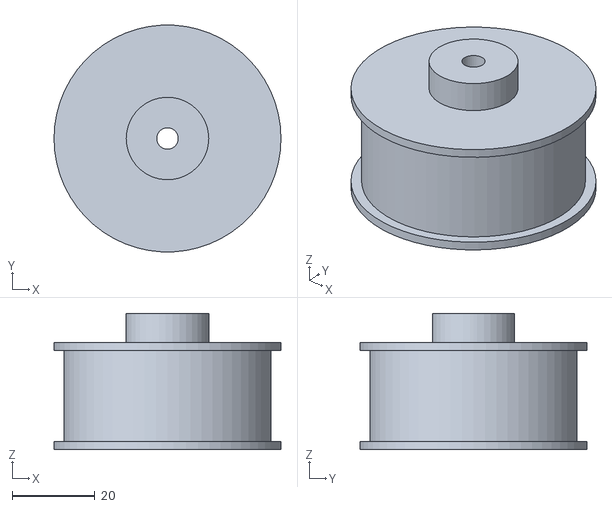
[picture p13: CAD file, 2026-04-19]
models/rin trasero.STL
55.0 x 54.9 x 33.0

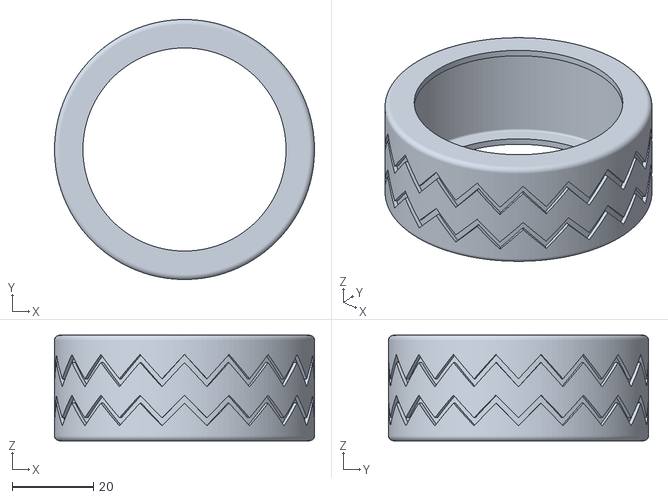
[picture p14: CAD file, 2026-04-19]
models/gomadellanta.stl
64.0 x 64.0 x 26.0

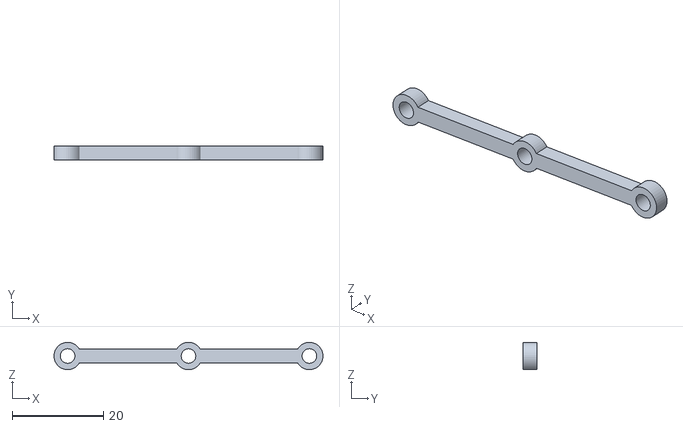
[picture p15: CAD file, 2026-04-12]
models/barilla direccional grande.STL
59.0 x 3.00 x 6.00

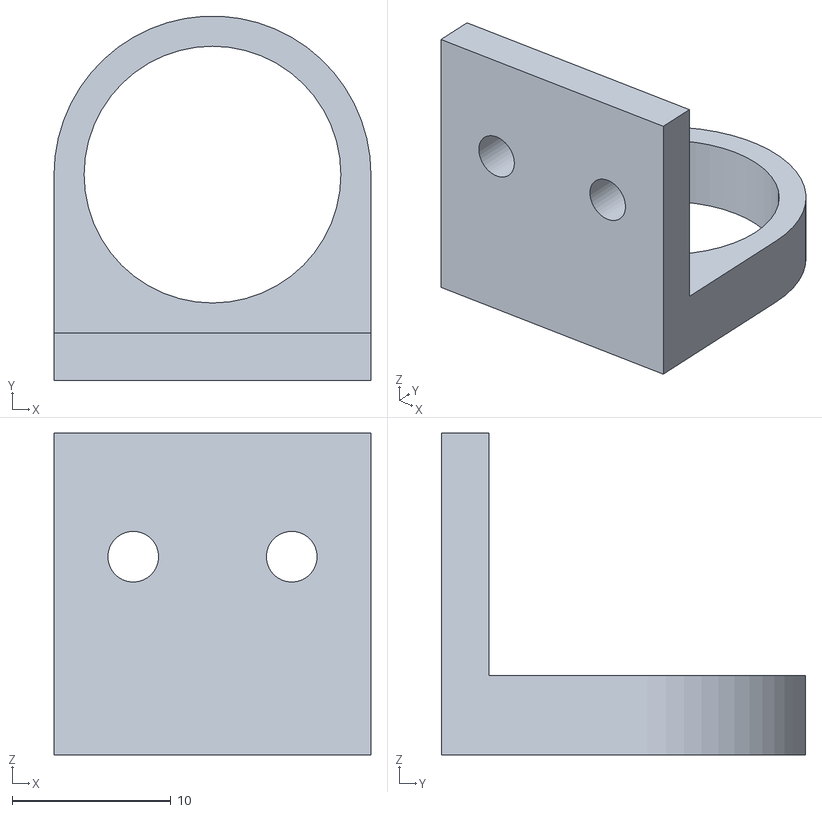
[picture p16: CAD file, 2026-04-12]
models/valero atras.STL
20.0 x 23.0 x 20.3

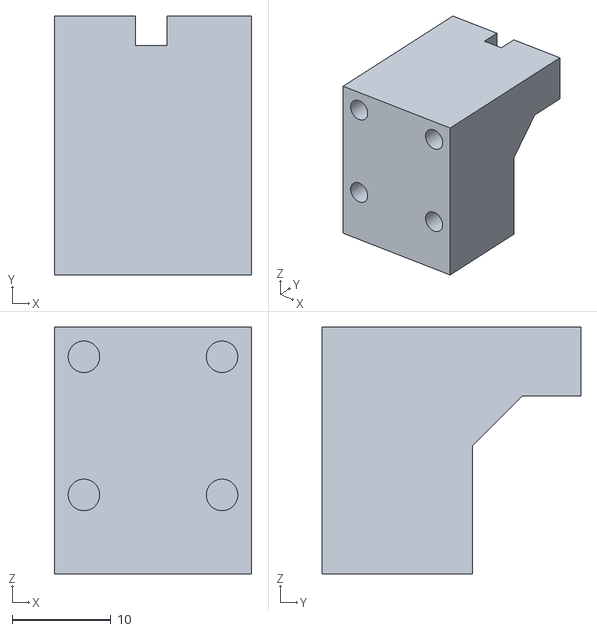
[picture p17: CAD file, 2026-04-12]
models/base servo.STL
20.0 x 26.2 x 25.0

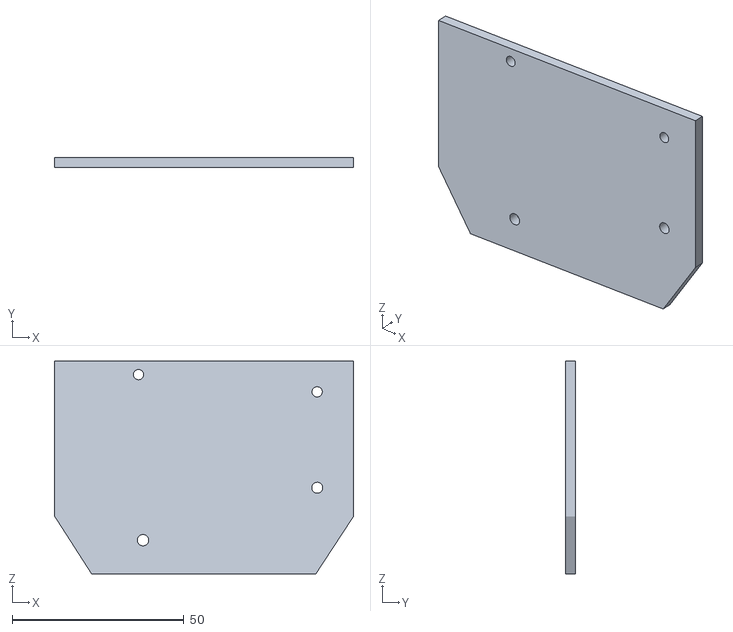
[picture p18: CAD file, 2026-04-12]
models/piso 3.STL
87.2 x 3.00 x 62.0

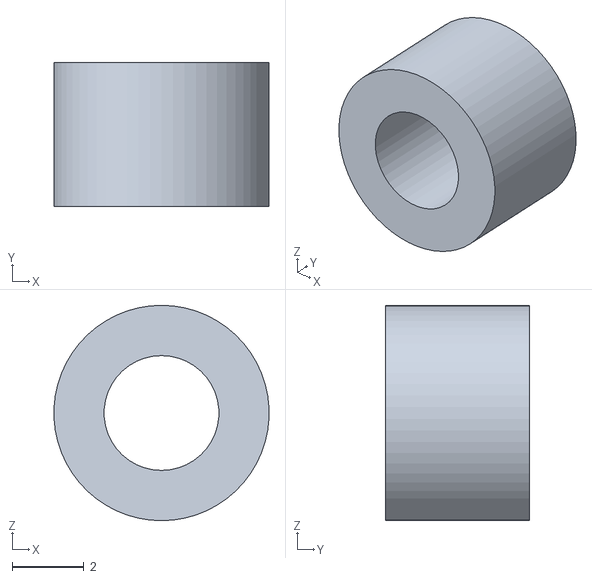
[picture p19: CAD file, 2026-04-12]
models/rondana.STL
5.99 x 4.00 x 6.00

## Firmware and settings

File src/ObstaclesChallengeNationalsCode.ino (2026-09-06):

#include <Arduino.h>
#include <ESP32Servo.h>
#include "WonderCam.h"

#define SDA 21
#define SCL 22

#define TRIG_FRENTE 33
#define ECHO_FRENTE 19
#define TRIG_DER 18
#define ECHO_DER 5
#define TRIG_IZQ 32
#define ECHO_IZQ 35
#define PIN_SERVO 17
#define PIN_BOTON 34

WonderCam Cam;
Servo Direccion;

const int PWMA = 14;
const int AIN1 = 12;
const int AIN2  =13;

#define Acentral 80
#define Areversa 51
#define Asalida_izquierda 45
#define Asalida_derecha   135

#define AesquiveRojo 111
#define AreacomodoRojo 51

#define AesquiveVerde 51
#define AreacomodoVerde 111

#define Tcentral 700
#define Tesquive 700
#define Treacomodo 500

#define Tgiro 1600
#define Talto 500
#define Tatras 1000

#define Tatras_salida     300
#define Tadelante_salida  350
#define Tadelante_afuera  1000
#define Tatras_Acomodo    600

#define VELOCIDAD_NORMAL 170
#define VELOCIDAD_GIRO 180
#define VELOCIDAD_ESQUIVE 200

#define Velocidad_salida  190

#define AREA_MINIMA_VERDE 6000
#define AREA_MINIMA_ROJO 3500
#define DISTANCIA_FRENTE 70

#define TOTAL_GIROS 12

bool robotActivo = false;

unsigned long lastUpdate  = 0;
const unsigned long updateInterval  = 100;

int area1 = 0, area2 = 0;
int centroX1 = 0, centroX2 = 0;
int centroY2 = 0;

float ulLecturaFrente = 999;
float ulLecturaDer = 999;
float ulLecturaIzq = 999;

int opcion = 0;

int contadorGiros = 0;

float leerDistancia(int trig, int echo) {
  digitalWrite(trig, LOW);
  delayMicroseconds(2);
  digitalWrite(trig, HIGH);
  delayMicroseconds(10);
  digitalWrite(trig, LOW);
  unsigned long duracion = pulseIn(echo, HIGH, 30000);
  if (duracion == 0) return -1;
  return duracion / 58.0;
}

void adelante(int velocidad) {
  digitalWrite(AIN1, LOW);
  digitalWrite(AIN2, HIGH);
  analogWrite(PWMA, velocidad);
}

void atras(int velocidad) {
  digitalWrite(AIN1, HIGH);
  digitalWrite(AIN2, LOW);
  analogWrite(PWMA, velocidad);
}

void moverServo(int angulo) {
  Direccion.write(angulo);
}

void detenerRobot() {
  moverServo(Acentral);
  analogWrite(PWMA, 0);
}

void esquivarRojo() {
  detenerRobot();
  delay(500);
  atras(VELOCIDAD_NORMAL);
  delay(500);
  detenerRobot();
  delay(500);
  adelante(VELOCIDAD_ESQUIVE);
  moverServo(AesquiveRojo + 10);
  delay(Tesquive);
  adelante(VELOCIDAD_ESQUIVE);
  moverServo(Acentral);
  delay(Tcentral);
  adelante(VELOCIDAD_ESQUIVE);
  moverServo(AreacomodoRojo - 10);
  delay(Treacomodo + 200);
  moverServo(Acentral);
}

void esquivarVerde() {
  detenerRobot();
  delay(500);
  atras(VELOCIDAD_NORMAL);
  delay(500);
  detenerRobot();
  delay(500);
  adelante(VELOCIDAD_ESQUIVE);
  moverServo(AesquiveVerde);
  delay(Tesquive);
  adelante(VELOCIDAD_ESQUIVE);
  moverServo(Acentral);
  delay(Tcentral);
  adelante(VELOCIDAD_ESQUIVE);
  moverServo(AreacomodoVerde);
  delay(Treacomodo);
  moverServo(Acentral);
}

void girarDerecha() {
  moverServo(Acentral + 40);
  adelante(VELOCIDAD_GIRO);
  delay(Tgiro);
  moverServo(Acentral);
  detenerRobot();
  delay(Talto);
  moverServo(Areversa);
  atras(VELOCIDAD_GIRO);
  delay(Tatras);
  detenerRobot();
  delay(500);
  adelante(VELOCIDAD_NORMAL);
  moverServo(Acentral);
  delay(1000);
}

void girarIzquierda() {
  moverServo(Acentral - 40);
  adelante(VELOCIDAD_GIRO);
  delay(Tgiro);
  moverServo(Acentral);
  detenerRobot();
  delay(Talto);
  moverServo(AesquiveRojo);
  atras(VELOCIDAD_GIRO);
  delay(Tatras);
  detenerRobot();
  delay(500);
  adelante(VELOCIDAD_NORMAL);
  moverServo(Acentral);
  delay(1000);
}

void salirEstacionamientoIzquierda() {
  moverServo(Asalida_izquierda);
  adelante(Velocidad_salida);
  delay(Tadelante_salida);
  detenerRobot();
  delay(500);
  moverServo(Asalida_derecha);
  atras(Velocidad_salida);
  delay(Tatras_salida);
  detenerRobot();
  delay(500);
  moverServo(Asalida_izquierda);
  adelante(Velocidad_salida);
  delay(Tadelante_afuera);
  detenerRobot();
  delay(500);
  moverServo(Asalida_derecha);
  adelante(Velocidad_salida);
  delay(Tadelante_afuera);
  detenerRobot();
  delay(500);
  moverServo(Asalida_izquierda);
  atras(Velocidad_salida);
  delay(Tatras_Acomodo);
  detenerRobot();
}

void salirEstacionamientoDerecha() {
  moverServo(Asalida_derecha);
  adelante(Velocidad_salida);
  delay(Tadelante_salida);
  detenerRobot();
  delay(500);
  moverServo(Asalida_izquierda);
  atras(Velocidad_salida);
  delay(Tatras_salida);
  detenerRobot();
  delay(500);
  moverServo(Asalida_derecha);
  adelante(Velocidad_salida);
  delay(Tadelante_afuera);
  detenerRobot();
  delay(500);
  moverServo(Asalida_izquierda);
  adelante(Velocidad_salida);
  delay(Tadelante_afuera);
  detenerRobot();
  delay(500);
  moverServo(Asalida_derecha);
  atras(Velocidad_salida);
  delay(Tatras_Acomodo);
  detenerRobot();
}

void setup() {
  Serial.begin(115200);

  Wire.begin(SDA, SCL);
  Wire.setClock(10000);

  Serial.println("A VER");
  Cam.begin();

  Cam.setLed(true);
  Serial.println("LUUUUUUUZ");

  delay(100);

  if (Cam.changeFunc(APPLICATION_COLORDETECT)) {
    Serial.println("Modo color activado correctamente");
  } else {
    Serial.println("ERROR: Falló al cambiar a modo color");
    // Podrías agregar un led de error aquí
  }
  pinMode(TRIG_FRENTE, OUTPUT); digitalWrite(TRIG_FRENTE, LOW);
  pinMode(ECHO_FRENTE, INPUT);
  pinMode(TRIG_IZQ,    OUTPUT); digitalWrite(TRIG_IZQ,    HIGH);
  pinMode(ECHO_IZQ,    INPUT);
  pinMode(TRIG_DER,    OUTPUT); digitalWrite(TRIG_DER,    HIGH);
  pinMode(ECHO_DER,    INPUT);

  Direccion.attach(PIN_SERVO);
  Direccion.write(Acentral);

  pinMode(AIN1, OUTPUT);
  pinMode(AIN2, OUTPUT);
  pinMode(PWMA, OUTPUT);
  detenerRobot();

  pinMode(PIN_BOTON, INPUT_PULLUP);
  Serial.println("Sistema listo");

}

void loop() {
  Cam.updateResult();

  float distFrente = leerDistancia(TRIG_FRENTE, ECHO_FRENTE);
  float distDer = leerDistancia(TRIG_DER, ECHO_DER);
  float distIzq = leerDistancia(TRIG_IZQ, ECHO_IZQ);

  if (distFrente > 0) ulLecturaFrente = distFrente;
  if (distDer > 0) ulLecturaDer = distDer;
  if (distIzq > 0) ulLecturaIzq = distIzq;

  Serial.print("F: ");
  Serial.println(ulLecturaFrente);

  unsigned long ahora = millis();
  if (ahora - lastUpdate < updateInterval) {
    return;
  }
  lastUpdate = ahora;

  if (!Cam.updateResult()) {
    Serial.println("Error");
    return;
  }

  if (!robotActivo && digitalRead(PIN_BOTON) == LOW) {
    delay(50);
    if (digitalRead(PIN_BOTON) == LOW) {
      Serial.println("Empieza");
      robotActivo = true;
      if (opcion == 0) {
        float Lizq = leerDistancia(TRIG_IZQ, ECHO_IZQ);
        float Lder = leerDistancia(TRIG_DER, ECHO_DER);
        if (Lizq > 0) ulLecturaIzq = Lizq;
        if (Lder > 0) ulLecturaDer = Lder;

        if (ulLecturaDer > ulLecturaIzq) {
          opcion = 1;
          salirEstacionamientoDerecha();
        } else {
          opcion = 2;
          salirEstacionamientoIzquierda();
        }
      }
    }
  }

  if (!robotActivo) {
    detenerRobot();
    return;
  }

  area1 = 0;
  area2 = 0;
  centroX1 = 0;
  centroX2 = 0;
  centroY2 = 0;

  bool color1Detectado = Cam.colorIdDetected(1);
  bool color2Detectado = Cam.colorIdDetected(2);

  if(color1Detectado) {
    WonderCamColorDetectResult C1;
    Serial.print("Primer color");
    if(Cam.colorId(1, &C1)){
      centroX1 = C1.x + (C1.w / 2);
      area1 = C1.w * C1.h;
      Serial.print("ROJO | X="); Serial.print(centroX1);
      Serial.print(" Area="); Serial.println(area1);
    }
  }
  if(color2Detectado) {
    WonderCamColorDetectResult C2;
    Serial.print("Segundo color");
    if(Cam.colorId(2, &C2)){
      centroX2 = C2.x + (C2.w / 2);
      centroY2 = C2.y + (C2.h / 2);
      if (centroY2 > 150) {
        area2 = 0;
      } else {
        area2 = C2.w * C2.h;
      }
      Serial.print("VERDE | X="); Serial.print(centroX2);
      Serial.print(" Area="); Serial.println(area2);
    }
  }

  if (area1 > 0 || area2 > 0) {

    if (area1 >= area2) {
      // ✅ Verde tiene prioridad
      if (area1 >= AREA_MINIMA_VERDE) {
        esquivarVerde();
      } else {
        int angulo = map(centroX1, 0, 320, 51, 111);
        moverServo(constrain(angulo, 51, 111));
        adelante(VELOCIDAD_NORMAL);
      }
    } else {
      // ✅ Rojo tiene prioridad
      if (area2 >= AREA_MINIMA_ROJO) {
        if (centroY2 >  150) {
          area2 = 0;
        } else {
          esquivarRojo();
        }
      } else {
        int angulo = map(centroX2, 0, 320, 51, 111);
        moverServo(constrain(angulo, 51, 111));
        adelante(VELOCIDAD_NORMAL);
      }
    }

  } else {
    // --- Sin colores → sensor frontal ---
    moverServo(Acentral);
    adelante(VELOCIDAD_NORMAL);
    Serial.print("Sin colores | F: ");
    Serial.println(ulLecturaFrente);

    if (ulLecturaFrente < DISTANCIA_FRENTE && (distIzq > 100 || distDer > 100)) {
      if (opcion == 1) {
        girarDerecha();
        contadorGiros++;
      } else if (opcion == 2) {
        girarIzquierda();
        contadorGiros++;
      }
      if (contadorGiros >= TOTAL_GIROS) {
        robotActivo = false;
      }
    }
  }
}

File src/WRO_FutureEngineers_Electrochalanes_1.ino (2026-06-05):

#include <Servo.h>

#define TRIG_FRENTE 8
#define ECHO_FRENTE 4
#define TRIG_IZQ    10
#define ECHO_IZQ    6
#define TRIG_DER    12
#define ECHO_DER    7
#define PIN_SERVO   9
#define PIN_BOTON   11

const int PWMA = 5;
const int AIN1 = 3;
const int AIN2 = 2;

Servo direccion;

#define CENTRO         81
#define VEL_NORMAL     90
#define VEL_GIRO       120
#define DISTANCIA_GIRO 50
#define TOTAL_GIROS    12
#define TGIRO          1650

bool robotActivo      = false;
float ulLecturaFrente = 999;
float ulLecturaDer    = 999;
float ulLecturaIzq    = 999;

double setpoint_Der = 40.0;
double setpoint_Izq = 40.0;

double Kp = 10.0;
double Ki = 0.05;
double Kd = 5.0;

double error          = 0;
double error_anterior = 0;
double suma_errores   = 0;

unsigned long tiempoPrevio = 0;
double dt = 0;

int contadorGiros = 0;
int opcion        = 0; // 0=sin definir, 1=derecha, 2=izquierda

float leerDistanciaFrente(int trig, int echo) {
  digitalWrite(trig, LOW);
  delayMicroseconds(2);
  digitalWrite(trig, HIGH);
  delayMicroseconds(10);
  digitalWrite(trig, LOW);
  unsigned long duracion = pulseIn(echo, HIGH, 30000);
  if (duracion == 0) return -1;
  return duracion / 58.0;
}

float leerDistancia(int trig, int echo) {
  float muestras[5];
  int validas = 0;

  for (int i = 0; i < 5; i++) {
    digitalWrite(trig, LOW);
    delayMicroseconds(2);
    digitalWrite(trig, HIGH);
    delayMicroseconds(10);
    digitalWrite(trig, LOW);
    unsigned long duracion = pulseIn(echo, HIGH, 30000);
    if (duracion > 0 && duracion < 30000) {
      muestras[validas++] = duracion / 58.0;
    }
    delay(30);
  }

  if (validas == 0) return -1;

  for (int i = 0; i < validas - 1; i++)
    for (int j = i + 1; j < validas; j++)
      if (muestras[i] > muestras[j]) {
        float tmp = muestras[i];
        muestras[i] = muestras[j];
        muestras[j] = tmp;
      }

  return muestras[validas / 2];
}

void moverServo(int angulo) {
  direccion.write(constrain(angulo, 0, 180));
}

void adelante(int velocidad) {
  digitalWrite(AIN1, HIGH);
  digitalWrite(AIN2, LOW);
  analogWrite(PWMA, velocidad);
}

void detenerRobot() {
  moverServo(CENTRO);
  analogWrite(PWMA, 0);
  error = 0; error_anterior = 0; suma_errores = 0;
}

void girarIzquierda() {
  moverServo(CENTRO - 40);
  adelante(VEL_GIRO);
  delay(TGIRO);
  moverServo(CENTRO);
  adelante(VEL_NORMAL);
  delay(1000);
  ulLecturaFrente = 999;
  error = 0; error_anterior = 0; suma_errores = 0;
  tiempoPrevio = millis();
  Serial.println("GIRANDO IZQUIERDA");
}

void girarDerecha() {
  moverServo(CENTRO + 40);
  adelante(VEL_GIRO);
  delay(TGIRO);
  moverServo(CENTRO);
  adelante(VEL_NORMAL);
  delay(1000);
  ulLecturaFrente = 999;
  error = 0; error_anterior = 0; suma_errores = 0;
  tiempoPrevio = millis();
  Serial.println("GIRANDO DERECHA");
}

void PIDderecho() {
  error = ulLecturaDer - setpoint_Der;

  double P = Kp * error;
  double D = Kd * ((error - error_anterior) / dt);
  double prueba = P + D + Ki * (suma_errores + error * dt);
  if (constrain(prueba, -20, 20) == prueba) {
    suma_errores += error * dt;
    suma_errores = constrain(suma_errores, -70, 70);
  }
  double I = Ki * suma_errores;
  double salidaPID = constrain(P + I + D, -20, 20);

  int anguloServo = CENTRO + (int)salidaPID;
  moverServo(anguloServo);
  adelante(VEL_NORMAL);
  error_anterior = error;

  Serial.print("PID_DER | Err: "); Serial.print(error);
  Serial.print(" | Srv: "); Serial.println(anguloServo);
}

void PIDizquierdo() {
  error = -ulLecturaIzq + setpoint_Izq;

  double P = Kp * error;
  double D = Kd * ((error - error_anterior) / dt);
  double prueba = P + D + Ki * (suma_errores + error * dt);
  if (constrain(prueba, -20, 20) == prueba) {
    suma_errores += error * dt;
    suma_errores = constrain(suma_errores, -70, 70);
  }
  double I = Ki * suma_errores;
  double salidaPID = constrain(P + I + D, -20, 20);

  int anguloServo = CENTRO + (int)salidaPID;
  moverServo(anguloServo);
  adelante(VEL_NORMAL);
  error_anterior = error;

  Serial.print("PID_IZQ | Err: "); Serial.print(error);
  Serial.print(" | Srv: "); Serial.println(anguloServo);
}

void setup() {
  Serial.begin(115200);

  pinMode(TRIG_FRENTE, OUTPUT); digitalWrite(TRIG_FRENTE, LOW);
  pinMode(ECHO_FRENTE, INPUT);
  pinMode(TRIG_IZQ,    OUTPUT); digitalWrite(TRIG_IZQ,    HIGH);
  pinMode(ECHO_IZQ,    INPUT);
  pinMode(TRIG_DER,    OUTPUT); digitalWrite(TRIG_DER,    HIGH);
  pinMode(ECHO_DER,    INPUT);

  direccion.attach(PIN_SERVO);
  direccion.write(CENTRO);

  pinMode(AIN1, OUTPUT);
  pinMode(AIN2, OUTPUT);
  pinMode(PWMA, OUTPUT);
  detenerRobot();

  pinMode(PIN_BOTON, INPUT_PULLUP);
}

void loop() {
  float distFrente = leerDistancia(TRIG_FRENTE, ECHO_FRENTE);
  float distDer    = leerDistanciaFrente(TRIG_DER, ECHO_DER);
  float distIzq    = leerDistanciaFrente(TRIG_IZQ, ECHO_IZQ);

  if (distFrente > 0) ulLecturaFrente = distFrente;
  if (distDer    > 0) ulLecturaDer    = distDer;
  if (distIzq    > 0) ulLecturaIzq    = distIzq;

  Serial.print("F: "); Serial.print(ulLecturaFrente);
  Serial.print(" | I: "); Serial.print(ulLecturaIzq);
  Serial.print(" | D: "); Serial.println(ulLecturaDer);

  if (!robotActivo && digitalRead(PIN_BOTON) == LOW) {
    delay(50);
    if (digitalRead(PIN_BOTON) == LOW) {
      // ✅ Dos setpoints independientes
      setpoint_Der = (ulLecturaDer < 400) ? ulLecturaDer : 40.0;
      setpoint_Izq = (ulLecturaIzq < 400) ? ulLecturaIzq : 40.0;
      Serial.print("SP_Der: "); Serial.print(setpoint_Der);
      Serial.print(" | SP_Izq: "); Serial.println(setpoint_Izq);
      tiempoPrevio = millis();
      robotActivo  = true;
    }
  }

  if (!robotActivo) {
    detenerRobot();
    return;
  }

  unsigned long ahora = millis();
  dt = (ahora - tiempoPrevio) / 1000.0;
  if (dt < 0.001) dt = 0.001;
  tiempoPrevio = ahora;

  // --- Giro ---
  if (ulLecturaFrente < DISTANCIA_GIRO) {

    if (opcion == 0) {
      // ✅ Primer giro — determinar dirección
      detenerRobot();
      delay(1500);

      // Releer sensores tras detenerse
      float lIzq = leerDistancia(TRIG_IZQ, ECHO_IZQ);
      float lDer = leerDistancia(TRIG_DER, ECHO_DER);
      if (lIzq > 0) ulLecturaIzq = lIzq;
      if (lDer > 0) ulLecturaDer = lDer;

      if (ulLecturaIzq > ulLecturaDer) {
        opcion = 1; // ✅ Más espacio a la izquierda → girar derecha
        girarIzquierda();
      } else {
        opcion = 2; // ✅ Más espacio a la derecha → girar izquierda
        girarDerecha();
      }

    } else if (opcion == 1) {
      girarIzquierda();   // ✅ Mantener dirección
    } else if (opcion == 2) {
      girarDerecha(); // ✅ Mantener dirección
    }

    contadorGiros++;
    Serial.print("Giro #"); Serial.print(contadorGiros);
    Serial.print("/"); Serial.println(TOTAL_GIROS);

    if (contadorGiros >= TOTAL_GIROS) {
      detenerRobot();
      robotActivo = false;
      Serial.println("=== 3 VUELTAS COMPLETADAS ===");
    }
    return;
  }
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

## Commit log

2026-04-12 Lista de componentes
    En este commit se agregó la lista de materiales
2026-04-12 Archivos STL
    Incluye los archivos de las piezas que componen al robot, estos se imprimen o cortan según las preferencias del usuario.
    [barilla direccional - copia.STL, barilla direccional grande.STL, base camara.stl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]
2026-04-15 criterio 1 y 2
    se agregó información para cumplir con los primeros 2 criterios
2026-04-15 cambio ligero
    eliminé algo irrelevante como la sección "other"
2026-06-05 Revise README for Arduino UNO R4 Minima and HC-SR04
    Updated README to reflect changes in hardware specifications and sensor models.
2026-06-05 new components bases
    [base camara - Part 1.stl, base camara - Part 2.stl, baseultrasónicos.stl]
2026-09-06 New Schematics
2026-09-06 New bases
    [base esp.STL, girador.STL, piso 2.STL]
2026-09-07 Update README with shield design and power details
    Added details about shield design and power distribution.
2026-09-07 Revise material update for chassis and steering system
    Updated material specifications for chassis and steering components to reflect the use of black PETG instead of PLA, highlighting the benefits of the new material.
2026-09-07 Update README with wireless and GPIO voltage details
    Clarified the limitations and risks associated with wireless communication and GPIO voltage levels in the README.
